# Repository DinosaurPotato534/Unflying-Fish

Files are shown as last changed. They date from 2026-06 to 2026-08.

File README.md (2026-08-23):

# Unflying Fish

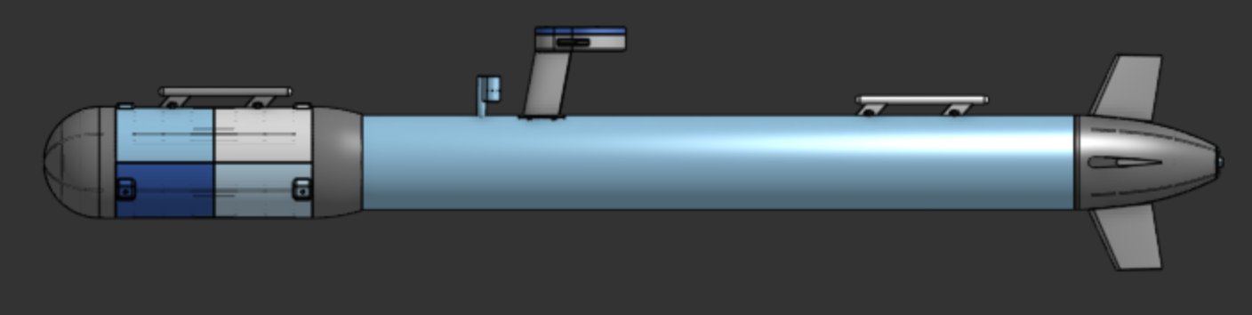
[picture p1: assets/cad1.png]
sub


The main goal of the project was to create a full autonomous underwater vehicle capable of traveling below the surface with no signal. Water completely blocks out both GPS and WIFI, so we will have no connection at all once it submerges below the surface. Thus, the submarine can use gps to navigate above water to various waypoints and use dead-reckoning when navigating underwater.

https://cad.onshape.com/documents/526140a6d93d9e122471a075/w/3eb4851c7e5a9558da121771/e/749db0c17ff4b1f534fcc59e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

## Motivation
Both of us (Shaan and Dimitri) have had an interest in amphibious vehicles capable of transferring between water, land, and air. This is one of our first steps in testing underwater systems and learning more about process.

## Design

### Ribbed Hull
For all the 3D printed parts be decided to go with a modular ribbed hull design as it was significantly more efficient in filament. It also greatly reduced support material and made many parts much more printable. The hull works by having a mostly thin outer shell (1.4mm) with several 4mm ribs running across. Then, rings would be nested in these ribs to further support both the walls and anything inside.

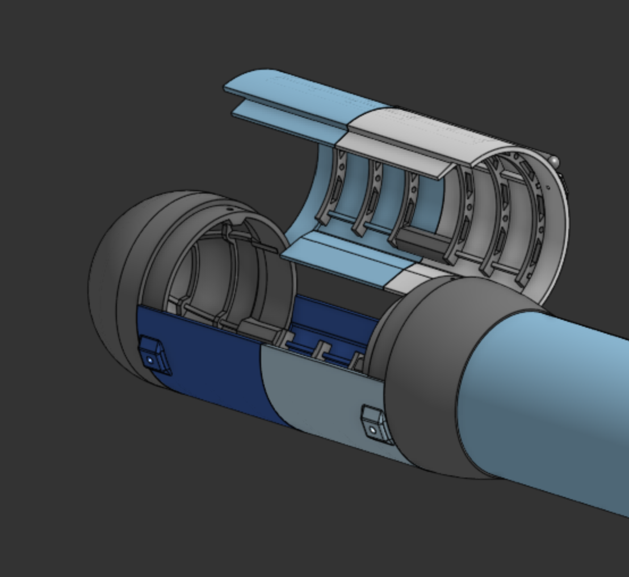
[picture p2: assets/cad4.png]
ribs


### Ballast System
One of the more complicated aspects of the sub was the ballast system. Many other submarines use compressed air to fill a tank, but that requires a pump and only functions a few times before air runs out. Instead, we decided to use a dual approach with a lead screw driving two syringes for precise ballast control. Then, once at the surface and air-pump will fill up plastic bags to push the sub fully out of the water.

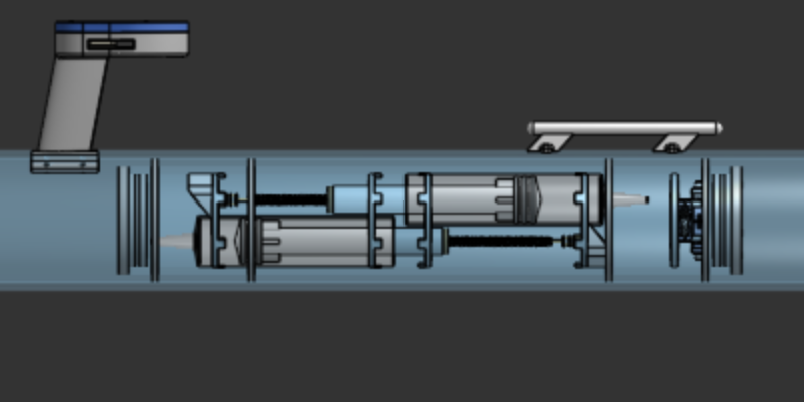
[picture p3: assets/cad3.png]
ballast


### Antenna Tower
The antenna tower is relatively simple, housing both the GPS and ESP-32 Wifi antenna for signal. It also has a window to house LEDs to make the sub more visible when it is barely emerged from the surface.

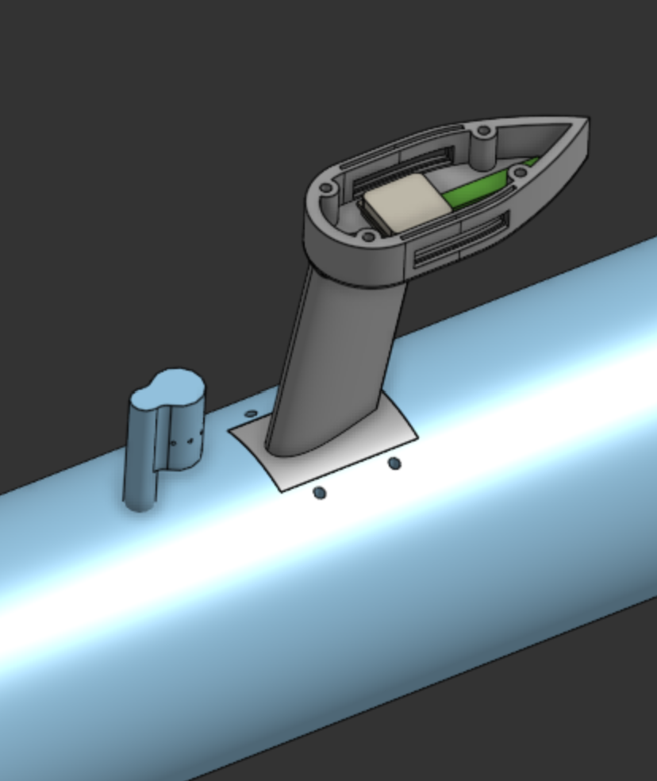
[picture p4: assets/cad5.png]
antennas


## Assembling
The main hull consists of a 4in pvc pipe, which everything else will be connected to. Antenna tower, for example, will be epoxied and bolted into the top surface of the pipe, with holes drilled through for wires.

The 3d printed nose will be assembled in multiple smaller parts first. Each quarter will be printed with vertically. Then, the flat ring ribs will be slid down the hull until it reaches its desired spot and epoxied into place. The tail will also be assembled in a similar way.

The electronics bay is a pvc pipe housing all the main electronics, such the battery and flight controller, and will removable from the nose. The nose compartment, which was seen earlier and can be opened, will be close using hose clamps

The end caps for both electronic bays will be 3d printed, but filled with epoxy to seal them. An o-ring will be added on a notch to complete the seal.

The ballast system will be assembled by putting the syringes into custom mounts in the pipe. Then the syringe head will be connected to the lead screw, which is driven by a small dc motor.
The servos controlling the tail flaps will also be in this compartment. They will be sealed by rubber bellows and have push/pull rods leading to the back.

## Electronics
The project features a custom control board with all sensors soldered, with the exception of a few modules which we opted to be breakouts to limit corruption of signal. The board is optimized to limit noise, and includes a ground pour. The board was fully designed in KiCad within the size constraints laid out by CAD.

The craft is powered by an ESP32 S3 with a 4S LiPo battery.

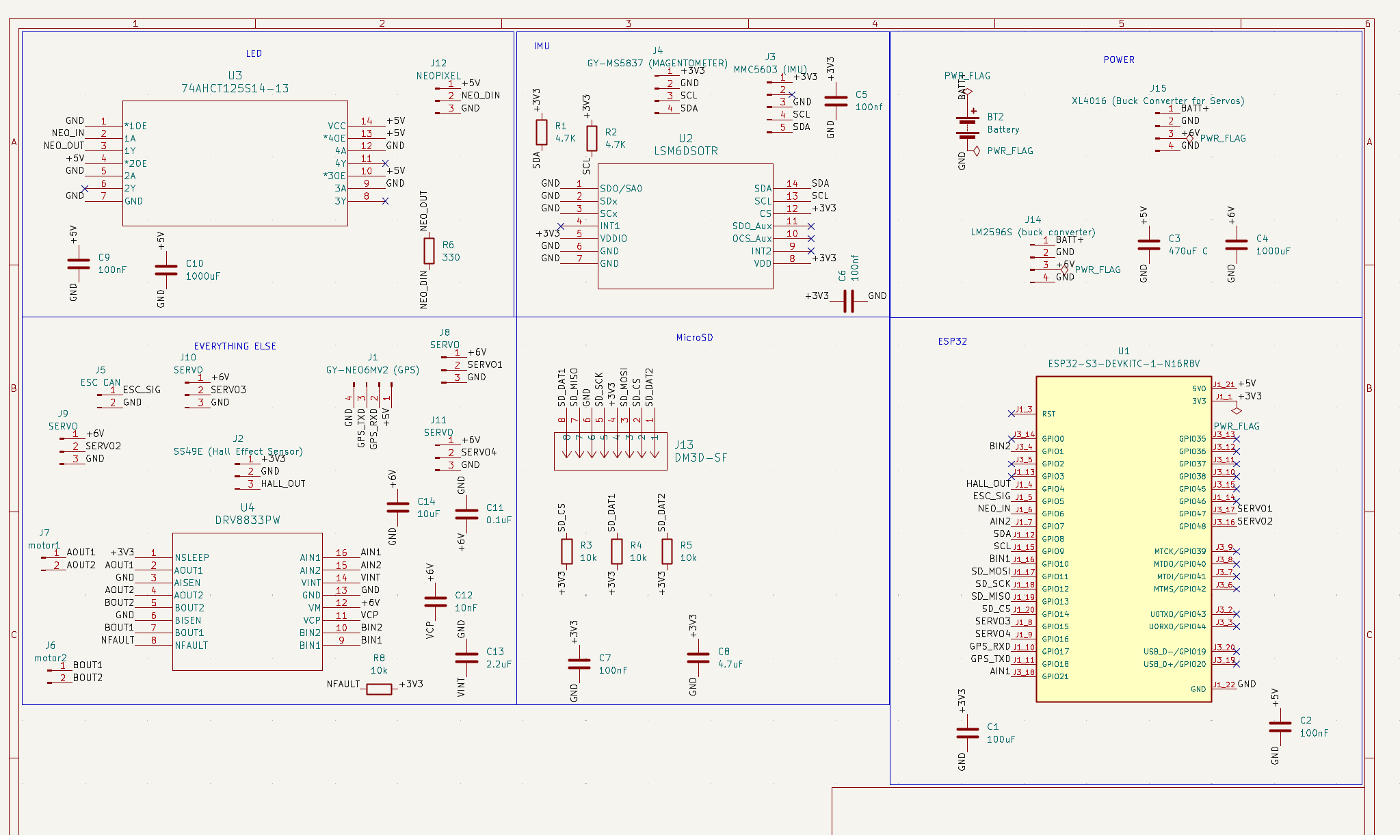
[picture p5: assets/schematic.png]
schematic

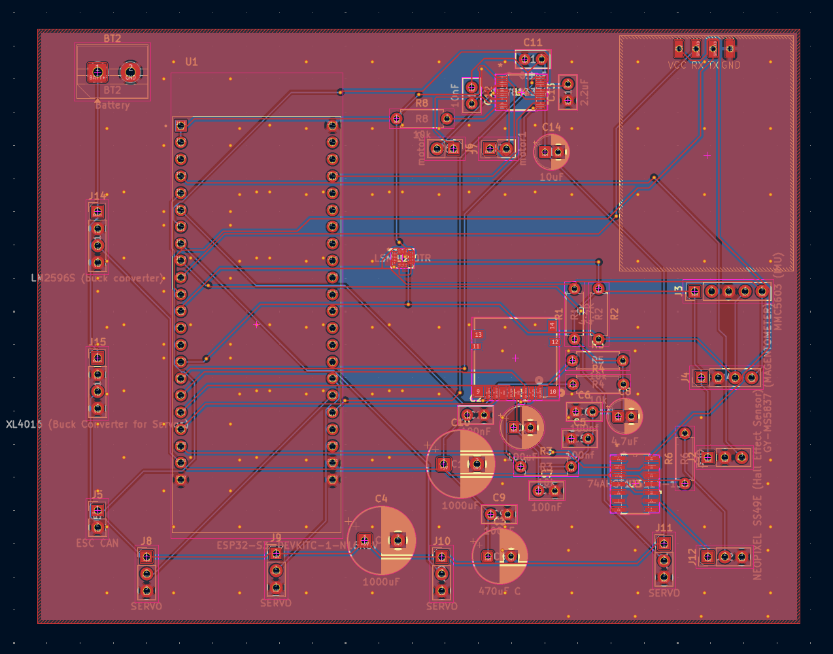
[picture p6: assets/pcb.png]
pcb


## Software
The projects code will be written in PlatformIO and feature a web-based interface to launch missions, automatic surfacing, and fault-recovery. We will use dead-reckoning to localize the crafts position based on a number of sensors, including custom water flow rate, magnetometer, and gps re-centering on surface. We will account for current using the magnetometer, thrust, and flow rate sensor. The code architecture is fully defined, and the code will be written once the craft is built and verified to ensure efficiency and accuracy.

## Bill Of Materials
| Item | Quantity | Cost (USD) | Purchase Link |
|---|---:|---:|---|
| GPS | 1 | $8.99 | https://www.amazon.com/HiLetgo-GY-NEO6MV2-Controller-Ceramic-Antenna/dp/B01D1D0F5M |
| Hall Effect Sensor | 1 | $3.28 | https://www.aliexpress.us/item/3256808273062702.html |
| Magnets | 1 | $6.45 | https://www.aliexpress.us/item/3256810253099525.html |
| IMU | 1 | $4.84 | https://www.digikey.com/en/products/detail/stmicroelectronics/LSM6DSOTR/9586579 |
| Magnometer | 1 | $5.95 | https://www.adafruit.com/product/5579 |
| Pressure Sensor | 1 | $6.18 | https://www.aliexpress.us/item/3256809434459171.html |
| ESP32-S3 | 1 | $13.99 | https://www.amazon.com/ESP32-S3-DevKitC-1-Development-Dual-Core-Bluetooth/dp/B0GVSHT2Q2 |
| Main Motor | 1 | $29.10 | https://www.underwaterthruster.com/products/apisqueen-brushless-waterproof-motor-2828-12v-16v-500kv-for-underwater-thruster-boat-rov |
| ESC | 1 | $17.64 | https://www.underwaterthruster.com/products/apisqueen-12-24v-3-6s-lipo-45a-bi-directional-esc-to-control-brushless-motors-propellers-in-forward-or-reverse-rotation |
| 4S LIPO | 1 | $26.99 | https://www.amazon.com/OVONIC-Battery-2200mAh-Connector-Quadcopter/dp/B0D8SF1C9K |
| Buck Converter | 1 | $11.20 | https://www.aliexpress.us/item/3256808194722756.html |
| LIPO Converter | 1 | $6.58 | https://www.aliexpress.us/item/3256810183858580.html |
| Wires | 1 | $11.56 | https://www.aliexpress.us/item/3256805055649344.html |
| Resistors | 1 | $6.49 | https://www.amazon.com/Resistor-Resistors-Assortment-Breadboard-Electronics/dp/B0F4P352BB |
| Servos (Pack of 4) | 1 | $17.98 | https://www.amazon.com/Deegoo-FPV-Servo-MG995-Metal-Gear/dp/B07NQJ1VZ2 |
| Breakout (Servos) | 1 | $9.45 | https://www.aliexpress.us/item/3256809858578105.html |
| Power Switch | 1 | $2.27 | https://www.aliexpress.us/item/3256809415854105.html |
| Fuses | 1 | $6.76 | https://www.aliexpress.us/item/3256812122080166.html |
| Capacitors | 1 | $9.99 | https://www.amazon.com/ALLECIN-Electrolytic-Capacitor-Assortment-Kit/dp/B0C1VBXCQM |
| Fuse Mounts | 1 | $11.12 | https://www.aliexpress.us/item/3256808052693050.html |
| Servo Connectors and Crimper | 1 | $24.99 | https://www.amazon.com/Female-Connector-Crimping-Compatible-Spektrum/dp/B0BGX7157Y |
| LEDs | 1 | $8.18 | https://www.aliexpress.us/item/3256806580504872.html |
| Level Shifter for LEDs | 1 | $0.26 | https://www.digikey.com/en/products/detail/diodes-incorporated/74AHCT125S14-13/7724623 |
| GPS Extension Cable | 1 | $6.99 | https://www.amazon.com/POBADY-Female-1-37mm-Low-Loss-Extension/dp/B0C8M8PCJ2 |
| Micro SD Slot | 1 | $2.32 | https://www.digikey.com/en/products/detail/hirose-electric-co-ltd/DM3D-SF/1786510 |
| Decoupling Capacitor | 1 | $2.68 | https://www.aliexpress.us/item/3256811909247133.html |
| Ballast Motor | 2 | $5.93 | https://www.aliexpress.us/item/3256807765699539.html |
| DC Motor Driver | 1 | $2.70 | https://www.digikey.com/en/products/detail/texas-instruments/DRV8833PW/4251165 |
| Ballast Air Motor | 1 | $8.54 | https://www.amazon.com/Jadeshay-Micro-Vacuum-Electric-PumpingBooster/dp/B089ZRYZV8 |
| M3 Screws and Heat Set Inserts | 1 | $15.99 | https://www.amazon.com/Threaded-Inserts-Plastic-3mm-10mm-Pringting/dp/B0GYRQG7F2 |
| PETG | 1 | $46.99 | https://www.amazon.com/SUNLU-PETG-Filament-1-75mm-Printer/dp/B0D1KBQ9VL |
| 4in PVC Pipe | 1 | $30.81 | https://www.homedepot.com/p/Charlotte-Pipe-4-in-x-10-ft-PVC-Schedule-40-DWV-Pipe-PVC074000600/100348477 |
| 3in PVC Pipe | 1 | $21.81 | https://www.homedepot.com/p/Charlotte-Pipe-3-in-x-10-ft-PVC-Schedule-40-Foam-Core-DWV-Pipe-PVC-04300-0600/100348479 |
| Silicone Tubing | 1 | $11.99 | https://www.amazon.com/Hooshing-Silicone-Flexible-Winemaking-Transfer/dp/B08PTXZ51Q |
| Hose Clamps (Tubing) | 1 | $5.19 | https://www.amazon.com/Jersvimc-12pcs-Stainless-Plated-Adjustable/dp/B0BZSKH624 |
| Hose Clamps (Hull) | 1 | $9.99 | https://www.amazon.com/EesTeck-Adjustable-Stainless-Clamps-Ducting/dp/B08B43QT5Y |
| Hose Clamps (Hull) Custom | 1 | $9.99 | https://www.amazon.com/OURU-Clamp-Fasteners-Stainless-Clamps/dp/B0BHZ93JTZ |
| O-Rings | 1 | $8.29 | https://www.amazon.com/XBVV-Nitrile-Assortment-Plumbing-Connections/dp/B0CBTYXVCV |
| Float Balls | 1 | $5.79 | https://www.amazon.com/uxcell-100pcs-Plastic-Bearing-Precision/dp/B0DZWW9C2V |
| Fiberglass Roll | 1 | $12.99 | https://www.amazon.com/Fiberglass-Chopped-Use%EF%BC%8CStrong-Structural-Reinforcement/dp/B0F8TR7Z27 |
| Hose Barb | 1 | $6.39 | https://www.amazon.com/HARFINGTON-Fitting-Splicer-Printing-Compressor/dp/B0FKMMKW9S |
| M4 Heat Set | 1 | $5.99 | https://www.amazon.com/Aoserge-100Pcs-Brass-Heat-Inserts/dp/B0FM3XZZ56 |
| Servo Bellows | 1 | $8.99 | https://www.amazon.com/10Pcs-Waterproof-Push-Rubber-Bellow/dp/B0749L64KJ |
| Syringe | 1 | $9.99 | https://www.amazon.com/Syringe-Without-Needle-Plastic-Syringes/dp/B0C39RWFJZ |
| 4in PVC Pipe O-Ring | 1 | $10.27 | https://www.amazon.com/240-Buna-N-Ring-Durometer-Round/dp/B0051XXMXI |
| 3in PVC Pipe O-Ring | 1 | $6.99 | https://www.amazon.com/uxcell-Nitrile-Automotive-Plumbing-Durometer/dp/B0FNMJNDVR |
| Lead Screws | 1 | $10.04 | https://www.aliexpress.us/item/3256805576723890.html |
| Galvanized Wire | 1 | $7.28 | https://www.amazon.com/Hillman-Galvanized-Solid-Utility-Silver/dp/B00FX982K8 |
| PCB | 1 | $9.00 | Shaan's Cart |
---
| Category | Cost (USD) |
|---|---:|
| AliExpress Shipping | $9.58 |
| Underwater Thruster Shipping | $19.00 |
| DigiKey Shipping | $6.65 |
| Adafruit Shipping | $6.52 |
| Home Depot Shipping | $0.00 |
| Amazon Shipping | $0.00 |
| JLC Shipping | $8.59 |
| **Total (pre-shipping)** | **$540.10** |
| **Total (post-shipping)** | **$590.44** |
---

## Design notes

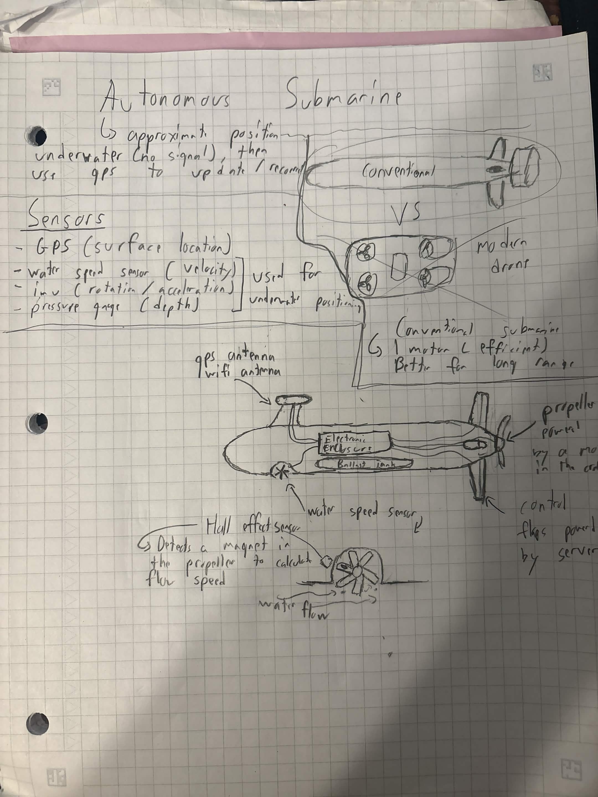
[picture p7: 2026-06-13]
assets/initial-design.jpg

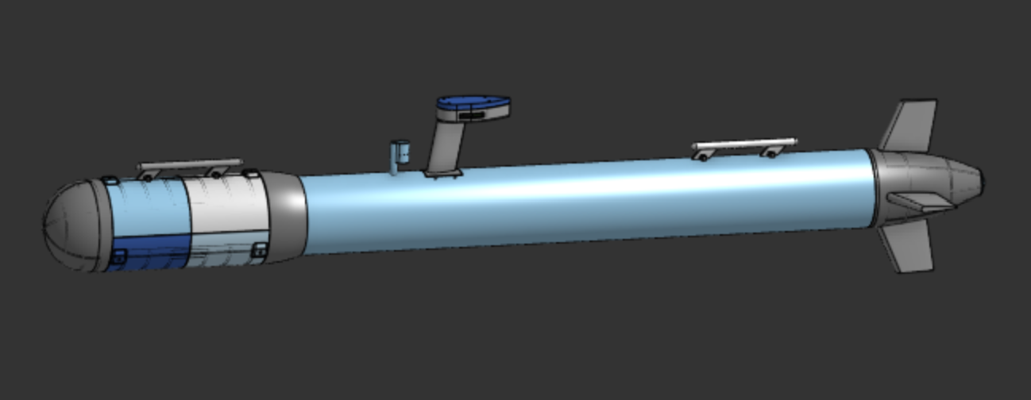
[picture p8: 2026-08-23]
assets/cad2.png

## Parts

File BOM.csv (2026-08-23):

Item | Quantity | Cost (USD) | Purchase Link
GPS | 1 | 8.99 | https://www.amazon.com/HiLetgo-GY-NEO6MV2-Controller-Ceramic-Antenna/dp/B01D1D0F5M?th=1
Hall Effect Sensor | 1 | 3.28 | https://www.aliexpress.us/item/3256808273062702.html?curPageLogUid=dLRSSyNQZlGG
Magnets | 1 | 6.45 | https://www.aliexpress.us/item/3256810253099525.html?curPageLogUid=lVdJJlFVtxi3
IMU | 1 | 4.84 | https://www.digikey.com/en/products/detail/stmicroelectronics/LSM6DSOTR/9586579
Magnometer | 1 | 5.95 | https://www.adafruit.com/product/5579
Pressure Sensor | 1 | 6.18 | https://www.aliexpress.us/item/3256809434459171.html?curPageLogUid=wnE0yvQv0ZN5
ESP32-S3 | 1 | 13.99 | https://www.amazon.com/ESP32-S3-DevKitC-1-Development-Dual-Core-Bluetooth/dp/B0GVSHT2Q2?s=electronics
Main Motor | 1 | 29.1 | https://www.underwaterthruster.com/products/apisqueen-brushless-waterproof-motor-2828-12v-16v-500kv-for-underwater-thruster-boat-rov
ESC | 1 | 17.64 | https://www.underwaterthruster.com/products/apisqueen-12-24v-3-6s-lipo-45a-bi-directional-esc-to-control-brushless-motors-propellers-in-forward-or-reverse-rot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
4S LIPO | 1 | 26.99 | https://www.amazon.com/OVONIC-Battery-2200mAh-Connector-Quadcopter/dp/B0D8SF1C9K?rnid=386636011
Buck Converter | 1 | 11.2 | https://www.aliexpress.us/item/3256808194722756.html?curPageLogUid=jlv8gK211gzo
LIPO Converter | 1 | 6.58 | https://www.aliexpress.us/item/3256810183858580.html?curPageLogUid=INr7DNhlEVcy
Wires | 1 | 11.56 | https://www.aliexpress.us/item/3256805055649344.html?curPageLogUid=t6OEkrk71Fn5
Resistors | 1 | 6.49 | https://www.amazon.com/Resistor-Resistors-Assortment-Breadboard-Electronics/dp/B0F4P352BB
Servos (Pack of 4) | 1 | 17.98 | https://www.amazon.com/Deegoo-FPV-Servo-MG995-Metal-Gear/dp/B07NQJ1VZ2
Breakout (Servos) | 1 | 9.45 | https://www.aliexpress.us/item/3256809858578105.html?curPageLogUid=Na8pSqTfC65l
Power Switch | 1 | 2.27 | https://www.aliexpress.us/item/3256809415854105.html?curPageLogUid=XTqRyCQitETI
Fuses | 1 | 6.76 | https://www.aliexpress.us/item/3256812122080166.html?curPageLogUid=fBiFVfnV41qJ
Capacitors | 1 | 9.99 | https://www.amazon.com/ALLECIN-Electrolytic-Capacitor-Assortment-Kit/dp/B0C1VBXCQM
Fuse Mounts | 1 | 11.12 | https://www.aliexpress.us/item/3256808052693050.html?curPageLogUid=lJ8DvXMhLjlW
Servo Connectors and Crimper | 1 | 24.99 | https://www.amazon.com/Female-Connector-Crimping-Compatible-Spektrum/dp/B0BGX7157Y
LEDs | 1 | 8.18 | https://www.aliexpress.us/item/3256806580504872.html?curPageLogUid=2U4FNTn9xuyi
Level Shifter for LEDs | 1 | 0.26 | https://www.digikey.com/en/products/detail/diodes-incorporated/74AHCT125S14-13/7724623
GPS Extenstion Cable | 1 | 6.99 | https://www.amazon.com/POBADY-Female-1-37mm-Low-Loss-Extension/dp/B0C8M8PCJ2
Micro SD Slot | 1 | 2.32 | https://www.digikey.com/en/products/detail/hirose-electric-co-ltd/DM3D-SF/1786510
Decoupling Capacitor | 1 | 2.68 | https://www.aliexpress.us/item/3256811909247133.html?curPageLogUid=iyZklXGvGMSM
Ballast Motor | 2 | 5.93 | https://www.aliexpress.us/item/3256807765699539.html?curPageLogUid=YaWPp7qkJByb
DC Motor Driver | 1 | 2.7 | https://www.digikey.com/en/products/detail/texas-instruments/DRV8833PW/4251165
Ballast Air Motor | 1 | 8.54 | https://www.amazon.com/Jadeshay-Micro-Vacuum-Electric-PumpingBooster/dp/B089ZRYZV8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
M3 Screws and Heat Set Inserts | 1 | 15.99 | https://www.amazon.com/Threaded-Inserts-Plastic-3mm-10mm-Pringting/dp/B0GYRQG7F2
PETG | 1 | 46.99 | https://www.amazon.com/SUNLU-PETG-Filament-1-75mm-Printer/dp/B0D1KBQ9VL
4in PVC Pipe | 1 | 30.81 | https://www.homedepot.com/p/Charlotte-Pipe-4-in-x-10-ft-PVC-Schedule-40-DWV-Pipe-PVC074000600/100348477
3in PVC Pipe | 1 | 21.81 | https://www.homedepot.com/p/Charlotte-Pipe-3-in-x-10-ft-PVC-Schedule-40-Foam-Core-DWV-Pipe-PVC-04300-0600/100348479
Silicone Tubing | 1 | 11.99 | https://www.amazon.com/Hooshing-Silicone-Flexible-Winemaking-Transfer/dp/B08PTXZ51Q
Hose Clamps (Tubing) | 1 | 5.19 | https://www.amazon.com/Jersvimc-12pcs-Stainless-Plated-Adjustable/dp/B0BZSKH624
Hose Clamps (Hull) | 1 | 9.99 | https://www.amazon.com/EesTeck-Adjustable-Stainless-Clamps-Ducting/dp/B08B43QT5Y
Hose Clamps (Hull) Custom | 1 | 9.99 | https://www.amazon.com/OURU-Clamp-Fasteners-Stainless-Clamps/dp/B0BHZ93JTZ
O-Rings | 1 | 8.29 | https://www.amazon.com/XBVV-Nitrile-Assortment-Plumbing-Connections/dp/B0CBTYXVCV
Float Balls | 1 | 5.79 | https://www.amazon.com/uxcell-100pcs-Plastic-Bearing-Precision/dp/B0DZWW9C2V?s=industrial&xpid=4f7Q3g9LQvipk
Fiberglass Roll | 1 | 12.99 | https://www.amazon.com/Fiberglass-Chopped-Use%EF%BC%8CStrong-Structural-Reinforcement/dp/B0F8TR7Z27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
Hose Barb | 1 | 6.39 | https://www.amazon.com/HARFINGTON-Fitting-Splicer-Printing-Compressor/dp/B0FKMMKW9S?s=industrial
M4 Heat Set | 1 | 5.99 | https://www.amazon.com/Aoserge-100Pcs-Brass-Heat-Inserts/dp/B0FM3XZZ56?s=industrial
Servo Bellows | 1 | 8.99 | https://www.amazon.com/10Pcs-Waterproof-Push-Rubber-Bellow/dp/B0749L64KJ
Syringe | 1 | 9.99 | https://www.amazon.com/Syringe-Without-Needle-Plastic-Syringes/dp/B0C39RWFJZ
4in PVC Pipe O-Ring | 1 | 10.27 | https://www.amazon.com/240-Buna-N-Ring-Durometer-Round/dp/B0051XXMXI
3in PVC Pipe O-Ring | 1 | 6.99 | https://www.amazon.com/uxcell-Nitrile-Automotive-Plumbing-Durometer/dp/B0FNMJNDVR
Lead Screws | 1 | 10.04 | https://www.aliexpress.us/item/3256805576723890.html?curPageLogUid=5QVhb0SJgDWp
Galvinzed Wire | 1 | 7.28 | https://www.amazon.com/Hillman-Galvanized-Solid-Utility-Silver/dp/B00FX982K8
PCB | 1 | 9 | Shaan's Cart
Shipping:
Aliexpress |  | 9.58
Underwater Thruster |  | 19
Digikey |  | 6.65
Adafruit |  | 6.52
Homedepot |  | 0
Amazon |  | 0
JLC |  | 8.59
Total (pre ship) |  | 540.1
Total (post shipping) |  | 590.44

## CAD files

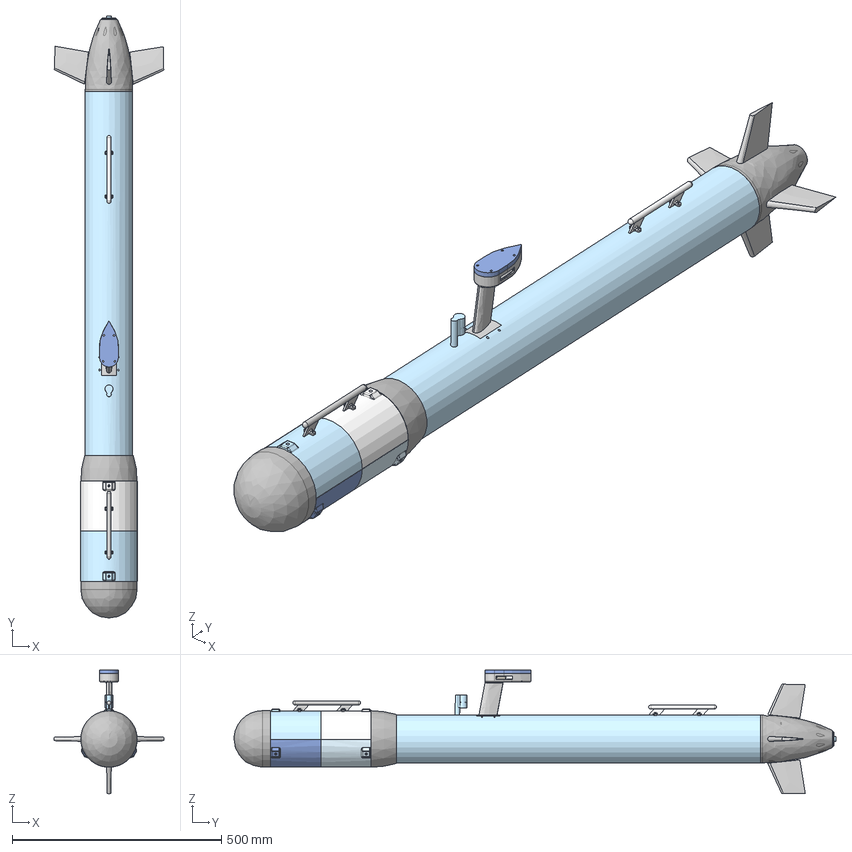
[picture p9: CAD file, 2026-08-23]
CAD/Assembled/Unflying Fish.step
261.5 x 1436.9 x 294.8 mm
Varsay?lan x 2
?? ????????? x 2
4" pvc electronics bay

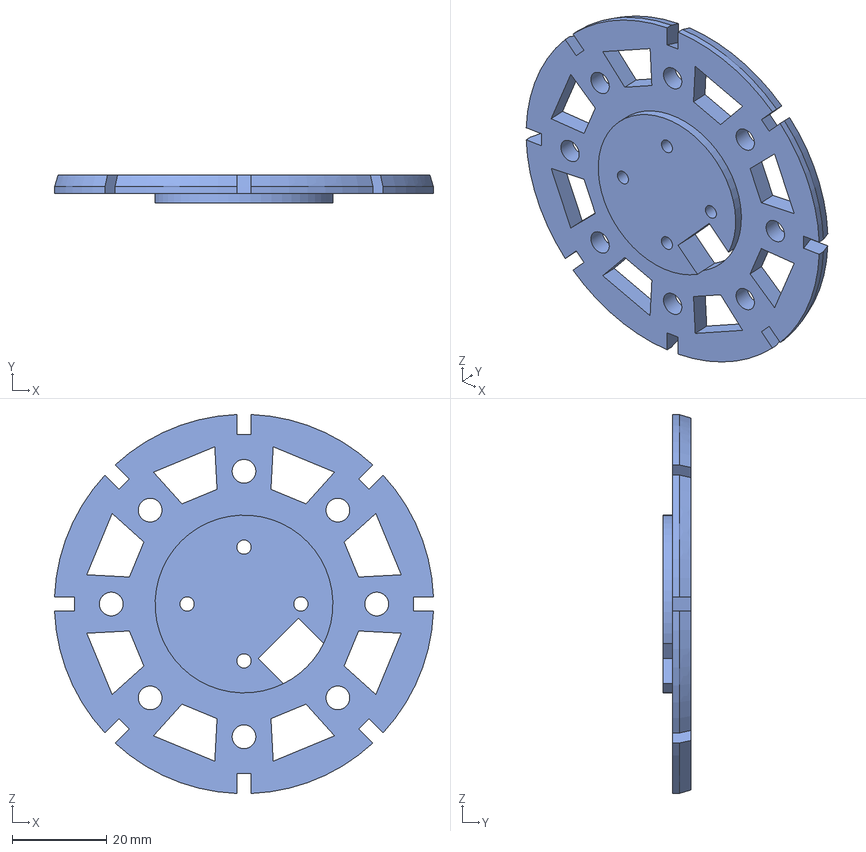
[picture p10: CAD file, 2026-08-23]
CAD/Parts/Tail - Motor Mount.step
79.9 x 6.00 x 79.9 mm

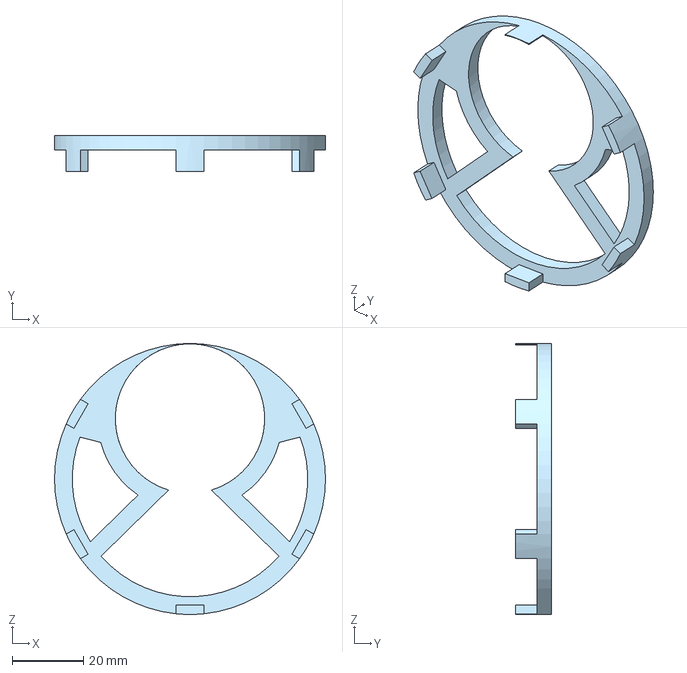
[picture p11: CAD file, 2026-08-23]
CAD/Parts/Mounts - Ballast Mounting Ring.step
76.2 x 10.0 x 76.2 mm

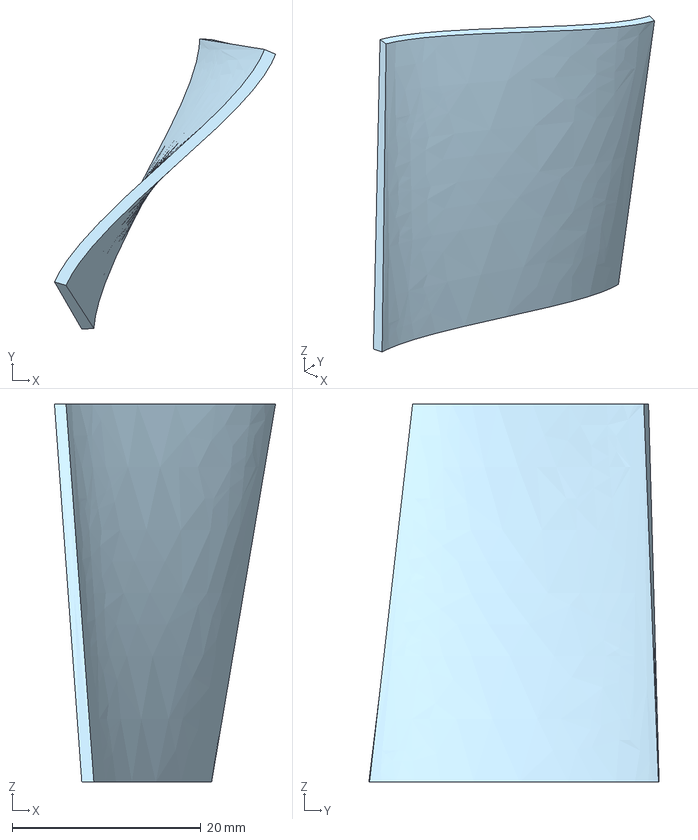
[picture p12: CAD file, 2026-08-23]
CAD/Parts/Prop - Prop Fin V1.step
23.4 x 30.7 x 40.0 mm

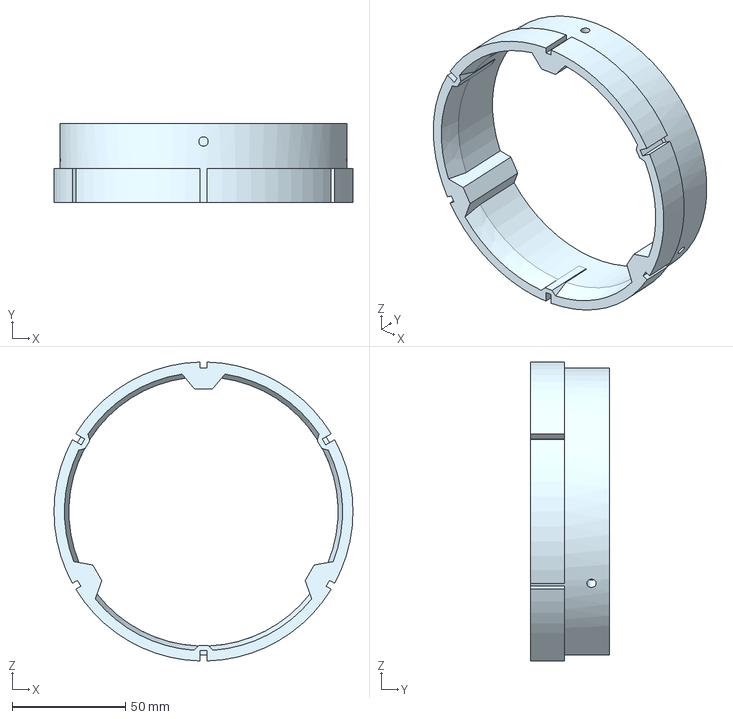
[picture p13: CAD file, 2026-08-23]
CAD/Parts/Nose V2 - Nose Ring3.step
132.2 x 35.0 x 132.2 mm

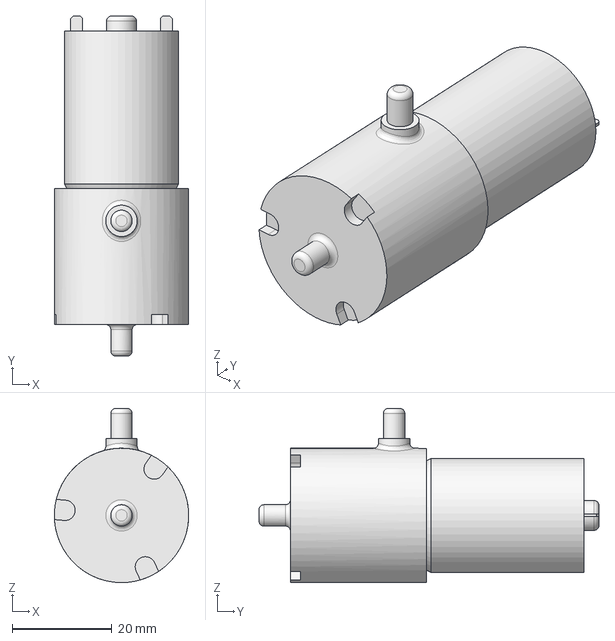
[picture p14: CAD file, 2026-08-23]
CAD/Parts/Part Studio 2 - Air Pump.step
27.0 x 68.3 x 35.0 mm

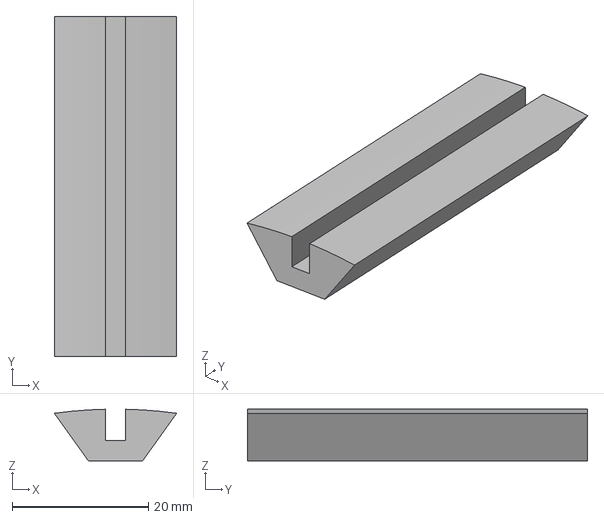
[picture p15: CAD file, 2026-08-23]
CAD/Parts/Buldge Shell - Hull Rib Aligner.step
18.0 x 50.0 x 7.58 mm

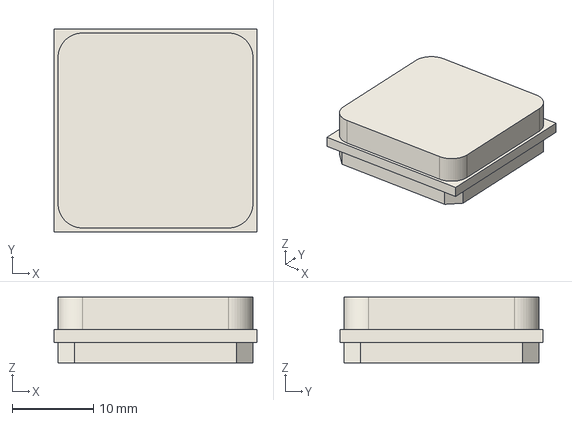
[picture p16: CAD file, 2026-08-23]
CAD/Parts/Gps Antenna - GPS.step
25.0 x 25.0 x 8.10 mm

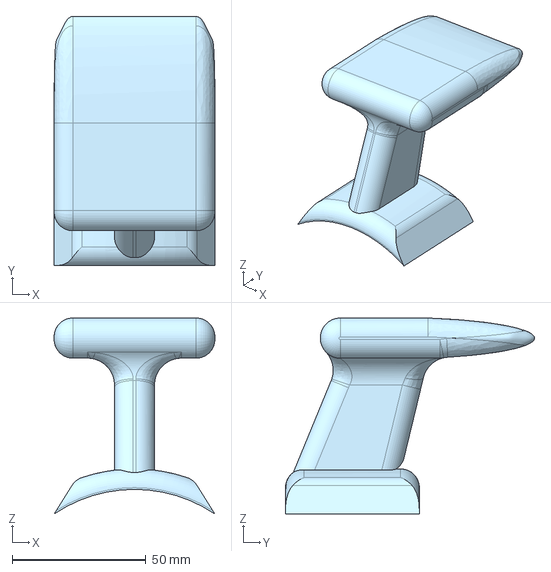
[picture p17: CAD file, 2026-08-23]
CAD/Parts/Antenna Tower V1 - Antenna Tower V1.step
60.0 x 93.0 x 73.2 mm

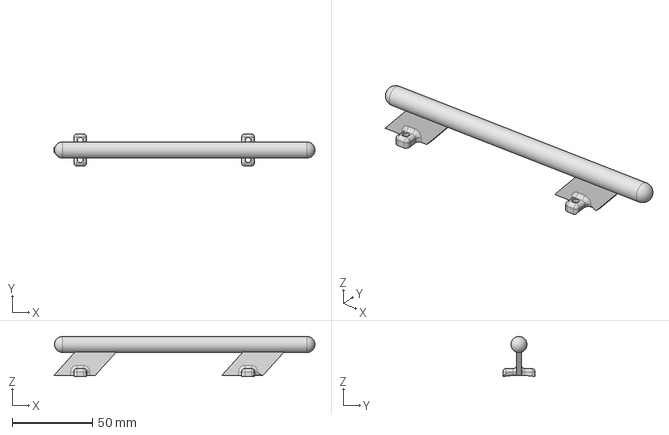
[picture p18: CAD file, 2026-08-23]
CAD/Parts/Handle - Large Handle.step
162.3 x 20.0 x 25.0 mm

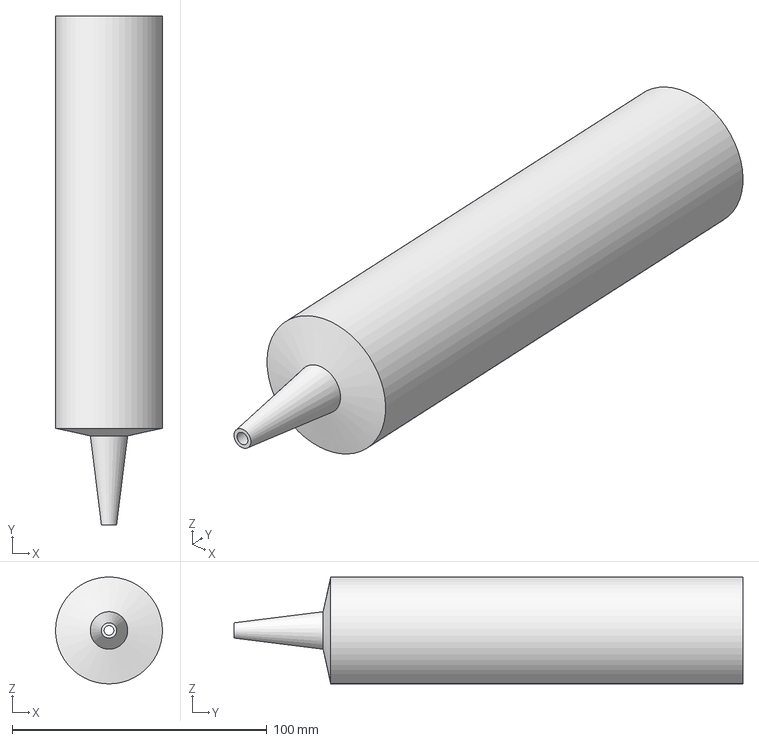
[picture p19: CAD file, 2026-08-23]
CAD/Parts/Part Studio 1 - Syringe.step
42.0 x 200.0 x 42.0 mm

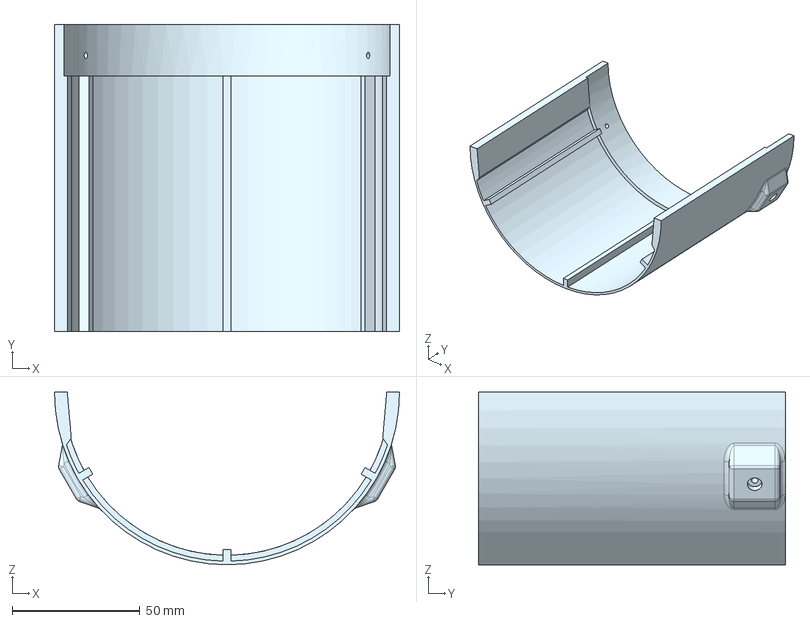
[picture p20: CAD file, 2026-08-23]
CAD/Parts/Buldge Shell - Hull Shell4.step
135.0 x 120.0 x 67.5 mm

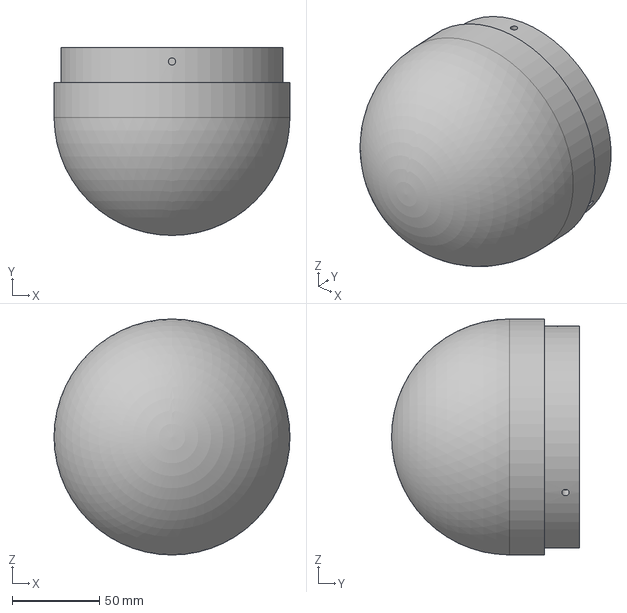
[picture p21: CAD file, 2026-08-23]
CAD/Parts/Nose V2 - Boolean Nose Cone.step
135.0 x 107.5 x 135.0 mm

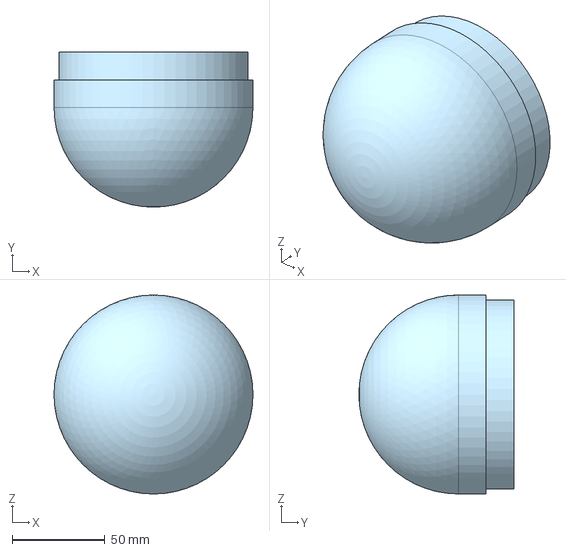
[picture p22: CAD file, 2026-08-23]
CAD/Parts/Nose - Nose Cone V1.step
107.1 x 83.5 x 107.1 mm

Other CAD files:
CAD/Parts/Tail - Tail to Pvc Ring.step
CAD/Parts/Float Valve - Float Valve.step
CAD/Parts/PVC Electronics Bay - 4in Cap.step
CAD/Parts/Tail - Tail Ring.step
CAD/3D Prints/Antenna Cap V2.stl
CAD/3D Prints/Antenna Tower V2.stl
CAD/3D Prints/Buldge Shell - Hull Half Ring Bottom.stl
CAD/3D Prints/Buldge Shell - Hull Half Ring.stl
CAD/3D Prints/Buldge Shell - Hull Rib Aligner.stl
CAD/3D Prints/Buldge Shell - Hull Shell1.stl
CAD/3D Prints/Buldge Shell - Hull Shell2.stl
CAD/3D Prints/Buldge Shell - Hull Shell3.stl
CAD/3D Prints/Buldge Shell - Hull Shell4.stl
CAD/3D Prints/Buldge Shell - Hull to PVC.stl
CAD/3D Prints/Float Valve - Float Valve.stl
CAD/3D Prints/Handle - Large Handle.stl
CAD/3D Prints/Handle - Small Handle.stl
CAD/3D Prints/Mounts - Ballast Mounting Ring.stl
CAD/3D Prints/Mounts - Motor Mount.stl
CAD/3D Prints/Mounts - Motor Mount1.stl
CAD/3D Prints/Mounts - Motor Mount2.stl
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

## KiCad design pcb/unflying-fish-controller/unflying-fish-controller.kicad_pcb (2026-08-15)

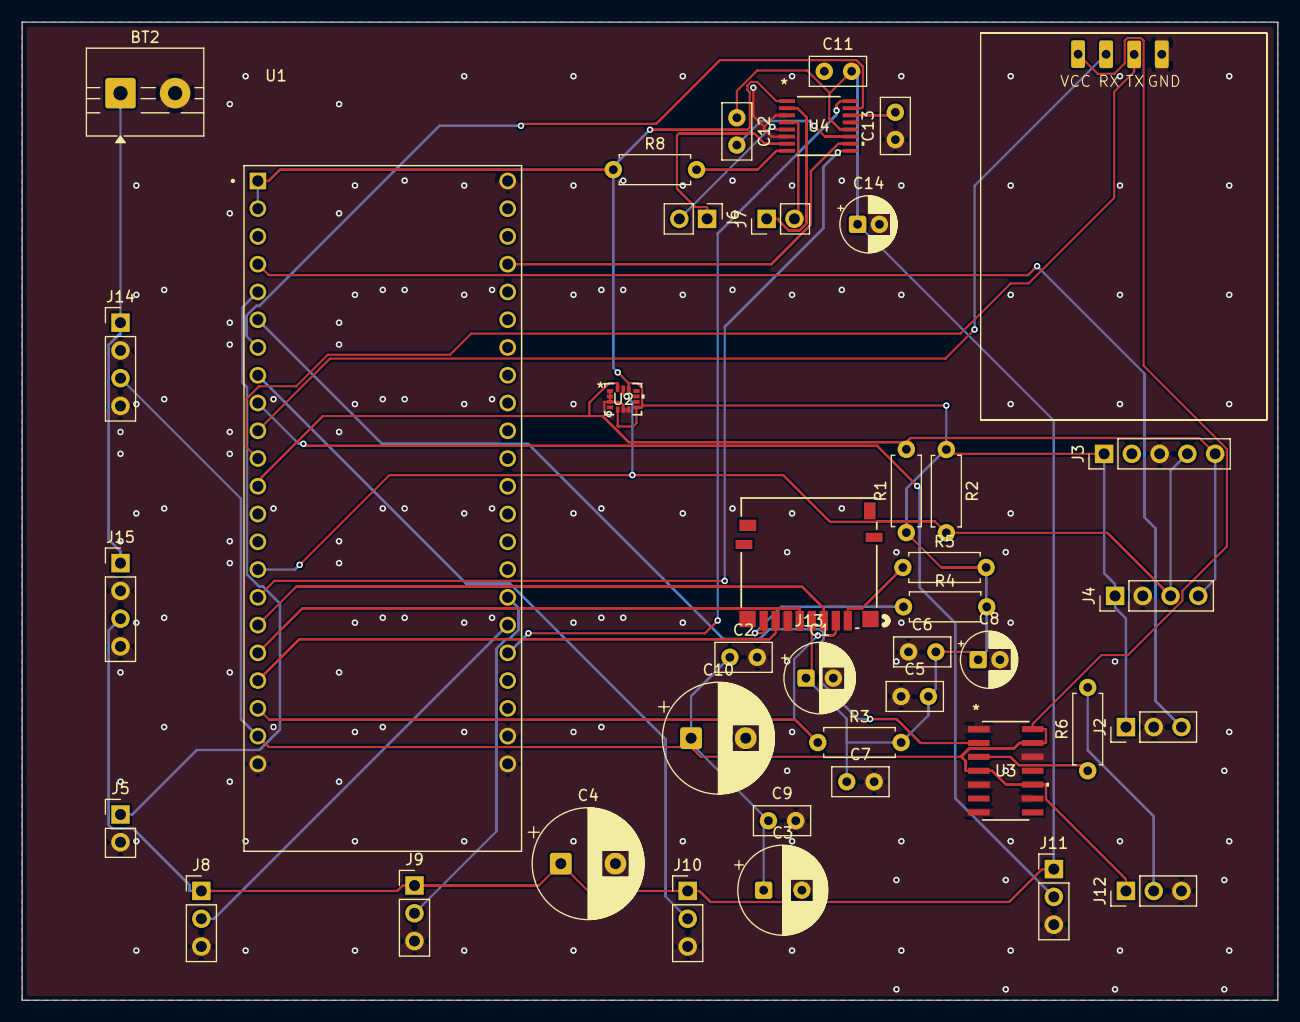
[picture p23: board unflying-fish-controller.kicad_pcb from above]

Board: 2 copper layers, 114.9 x 89.5 mm, 41 parts (0 on the bottom side), 35 nets.

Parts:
BT2: Battery; TerminalBlock_MaiXu_MX126-5.0-02P_1x02_P5.00mm
C1: 100uF; CP_Radial_D6.3mm_P2.50mm
C2, C7, C9: 100nF; C_Disc_D5.0mm_W2.5mm_P2.50mm
C3: 470uF C; CP_Radial_D8.0mm_P3.50mm
C4, C10: 1000uF; CP_Radial_D10.0mm_P5.00mm
C5, C6: 100nf; C_Disc_D5.0mm_W2.5mm_P2.50mm
C8: 4.7uF; CP_Radial_D5.0mm_P2.00mm
C11: 0.1uF; C_Disc_D5.0mm_W2.5mm_P2.50mm
C12: 10nF; C_Disc_D5.0mm_W2.5mm_P2.50mm
C13: 2.2uF; C_Disc_D5.0mm_W2.5mm_P2.50mm
C14: 10uF; CP_Radial_D5.0mm_P2.00mm
J1: GY-NEO6MV2 (GPS); GY-GPS6MV2
J2: SS49E (Hall Effect Sensor); PinHeader_1x03_P2.54mm_Vertical
J3: MMC5603 (IMU); PinHeader_1x05_P2.54mm_Vertical
J4: GY-MS5837 (MAGENTOMETER); PinHeader_1x04_P2.54mm_Vertical
J5: ESC CAN; PinHeader_1x02_P2.54mm_Vertical
J6: motor2; PinHeader_1x02_P2.54mm_Vertical
J7: motor1; PinHeader_1x02_P2.54mm_Vertical
J8, J9, J10, J11: SERVO; PinHeader_1x03_P2.54mm_Vertical
J12: NEOPIXEL; PinHeader_1x03_P2.54mm_Vertical
J13: DM3D-SF; CONN8_DM3D-SF_HIR
J14: LM2596S (buck converter); PinHeader_1x04_P2.54mm_Vertical
J15: XL4016 (Buck Converter for Servos); PinHeader_1x04_P2.54mm_Vertical
R1, R2: 4.7K; R_Axial_DIN0207_L6.3mm_D2.5mm_P7.62mm_Horizontal
R3, R4, R5, R8: 10k; R_Axial_DIN0207_L6.3mm_D2.5mm_P7.62mm_Horizontal
R6: 330; R_Axial_DIN0207_L6.3mm_D2.5mm_P7.62mm_Horizontal
U1: ESP32-S3-DEVKITC-1-N16R8V
U2: LSM6DSOTR
U3: 74AHCT125S14-13
U4: DRV8833PW; PW16_TEX

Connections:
3V3: C1.1, C5.2, C6.2, C7.1, C8.1, J2.1, J3.1, J4.1, J13.4, R1.1, R2.1, R3.2, R4.2, R5.2, R8.1, U1.J1_1 (3V3), U1.J1_2 (3V3), U2.5 (VDDIO), U2.8 (VDD), U2.12 (CS), U4.1 (NSLEEP)
/+5V: C2.1, C3.1, C9.1, C10.1, J1.26, J12.1, J14.3, U1.J1_21 (5V0), U3.4 (*2OE), U3.10 (*3OE), U3.13 (*4OE), U3.14 (VCC)
/+6V: C4.1, C11.2, C12.1, C14.1, J8.1, J9.1, J10.1, J11.1, J15.3, U4.12 (VM)
/AIN1: U1.J3_18 (GPIO21), U4.16 (AIN1)
/AIN2: U1.J1_7 (GPIO7), U4.15 (AIN2)
/AOUT1: J7.1, U4.2 (AOUT1)
/AOUT2: J7.2, U4.4 (AOUT2)
/BATT+: BT2.1 (+), J14.1, J15.1
/BIN1: U1.J1_16 (GPIO10), U4.9 (BIN1)
/BIN2: U1.J3_4 (GPIO1), U4.10 (BIN2)
/BOUT1: J6.1, U4.7 (BOUT1)
/BOUT2: J6.2, U4.5 (BOUT2)
/ESC_SIG: J5.1, U1.J1_5 (GPIO5)
/GPS_RXD: J1.27, U1.J1_10 (GPIO17)
/GPS_TXD: J1.28, U1.J1_11 (GPIO18)
/HALL_OUT: J2.3, U1.J1_4 (GPIO4)
/NEO_DIN: J12.2, R6.2
/NEO_IN: U1.J1_6 (GPIO6), U3.2 (1A)
/NEO_OUT: R6.1, U3.3 (1Y)
/NFAULT: R8.2, U4.8 (NFAULT)
/SCL: J3.4, J4.3, R2.2, U1.J1_15 (GPIO9), U2.13 (SCL)
/SDA: J3.5, J4.4, R1.2, U1.J1_12 (GPIO8), U2.14 (SDA)
/SD_CS: J13.2, R3.1, U1.J1_20 (GPIO14)
/SD_DAT1: J13.8, R4.1
/SD_DAT2: J13.1, R5.1
/SD_MISO: J13.7, U1.J1_19 (GPIO13)
/SD_MOSI: J13.3, U1.J1_17 (GPIO11)
/SD_SCK: J13.5, U1.J1_18 (GPIO12)
/SERVO1: J8.2, U1.J3_17 (GPIO47)
/SERVO2: J9.2, U1.J3_16 (GPIO48)
/SERVO3: J10.2, U1.J1_8 (GPIO15)
/SERVO4: J11.2, U1.J1_9 (GPIO16)
/VCP: C12.2, U4.11 (VCP)
/VINT: C13.2, U4.14 (VINT)
GND: BT2.2 (-), C1.2, C2.2, C3.2, C4.2, C5.1, C6.1, C7.2, C8.2, C9.2, C10.2, C11.1, C13.1, C14.2, J1.29, J2.2, J3.3, J4.2, J5.2, J8.3, J9.3, J10.3, J11.3, J12.3, J13.6, J14.2, J14.4, J15.2, J15.4, U1.J1_22 (GND), U1.J3_1 (GND), U1.J3_21 (GND), U1.J3_22 (GND), U2.1 (SDO/SA0), U2.2 (SDx), U2.3 (SCx), U2.6 (GND), U2.7 (GND), U3.1 (*1OE), U3.5 (2A), U3.7 (GND), U3.9 (3A), U3.12 (4A), U4.3 (AISEN), U4.6 (BISEN), U4.13 (GND)

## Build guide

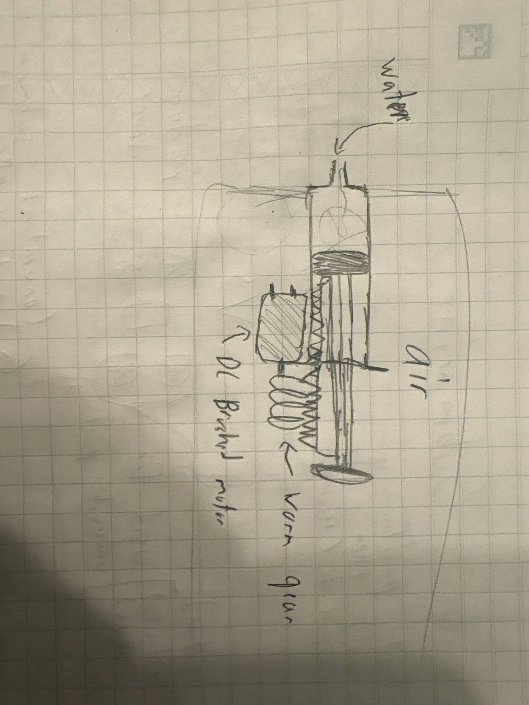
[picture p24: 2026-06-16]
assets/ballast-setup.webp

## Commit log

2026-06-14 update BOM
2026-06-16 kicad setup, initial footprints, dimitris ballasts, updated BOM
    [unflying-fish-controller.kicad_pcb, unflying-fish-controller.kicad_sch]
2026-06-17 BOM update
2026-06-28 new footprints type shit
2026-07-13 compact pcb slightly
    [unflying-fish-controller.kicad_pcb]
2026-08-15 add motor+driver for ballast
    [unflying-fish-controller.kicad_pcb, unflying-fish-controller.kicad_sch]
2026-08-23 Create Unflying Fish.step
    [Unflying Fish.step]
2026-08-23 readme + bom + assets
    [BOM.csv]
2026-08-23 Enhance README with motivation and assembly details
    Added sections on motivation and assembly instructions for the underwater vehicle project.
2026-08-23 parts and prints
    [8mm trapez mil - Lead Screw.step, Antenna Cap V2.step, Antenna Cap V2.stl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]
2026-08-23 Add CAD document link to README
    Added a link to the CAD document for reference.
2026-08-23 fixed Bom
    [BOM.csv]
2026-08-23 fix readme BOM
